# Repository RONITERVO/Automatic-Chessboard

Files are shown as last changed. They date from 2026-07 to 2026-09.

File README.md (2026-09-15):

# Automatic Chessboard

Arduino firmware for a CoreXY automatic chessboard with:

- two STEP/DIR stepper-motor drivers;
- an electromagnet for moving pieces;
- a multiplexed 8x8 reed-sensor matrix;
- a 16x2 I2C LCD and two-button interface; and
- the Micro-Max chess engine.

This is a substantially modified implementation of Greg06's
[Automated Chessboard](https://www.instructables.com/Automated-Chessboard/),
adapted around salvaged 3D-printer mechanics and the tested electronics
documented in this repository. See [design lineage and
attribution](ATTRIBUTION.md) and the repository's
[multi-license map](LICENSE.md) before redistributing it.

The [immersive 3D simulator](https://ronitervo.github.io/Automatic-Chessboard/) presents the complete assembly, chess pieces, setup process, physical controls, LCD, Arduino signal flow, wiring, and full-history replay in one shared React Three Fiber world. Visitors can use mouse, touch, or supported WebXR hands/controllers at real-world scale while the compiled production Nano HEX drives power-on, calibration, reed sensing, Micro-Max decisions, STEP/DIR motion, and magnet control. The standalone experience exposes Bluetooth as disconnected and never requests a real device. It is published automatically from `site/` after changes reach `main`.

## Demo

https://github.com/user-attachments/assets/5234de29-f910-4aed-a476-050bdca1a51d

## Hardware assumptions

The sketch uses the pin assignments and motion calibration in `global.h`. The
motor interface expects STEP/DIR drivers such as the A4988; motor current and
microstep selection are configured on the driver hardware.

For a complete beginner-oriented build, start with the
[`hardware` build guide](hardware/README.md). It includes protected power
wiring, a BOM, exact Nano/MKS Gen L V1.0 and 64-square sensor maps, staged assembly,
commissioning checks, diagrams, photographs of the working prototype, and
rework notes for the operational long PCB whose design predates the current
Bluetooth and A6 additions. Its archived KiCad source is reference-only, not a
current fabrication release. The 5 V buck output belongs on the Nano `5V` pin,
not `VIN`.

## Building

The release build is reproducible from PowerShell:

```powershell
./firmware/test.ps1 -InstallDependencies
```

It pins the AVR core and display libraries, validates the hardware contract,
runs tool tests, compiles the classic Nano and MKS Gen L V1.0 profiles, and
enforces flash/SRAM budgets. See [`firmware/README.md`](firmware/README.md) for the
modular source layout, explicit upload command, and contributor policy. The
main `.ino` can still be opened normally in Arduino IDE; its sibling `.ino`
tabs are compiled together automatically.

Review the pin assignments, travel calibration, limit-switch behavior, driver
current limit, and microstep settings before powering the motion hardware.

## Full validation without motion

When motors, piece magnets, or trustworthy reed readings are unavailable, run:

```powershell
./test-no-motion.ps1 -Port COM7
```

The workflow compiles the Nano firmware, enforces its memory budgets, exhaustively
tests the motionless `PLAN` / `DRAG` / `COMMIT` occupancy model, runs Windows and
Android planner/protocol/simulator tests, builds both apps, and optionally samples
the real Nano over USB. The COM probe is allowlisted to `HELLO 5.0.1`, `INFO`,
`TELEM`, and `BOARD`; it validates BOARD framing but does not require any particular
occupancy. It never uploads firmware or requests calibration, motor steps, magnet
power, or a chess move.

The probe first tries to keep DTR/RTS inactive. If a classic Nano does not
answer without its normal USB reset, use `-AllowSerialReset` only after checking
that firmware startup cannot energize the mechanism; this still does not send
an upload or any motion-capable protocol command.

This is the strongest release test possible without actuation, but it cannot prove
motor direction or step accuracy, magnet current/pickup/release, reed wiring and
orientation, mechanical clearance, homing repeatability, or physical collision
behavior. Those remain staged commissioning checks.

## Windows and Bluetooth companion

`windows_app` is the public-ready, open-source Windows monitor and companion for
this firmware. Windows runs Stockfish 18 and full chess rules while the Nano
retains motor timing, sensor scanning, calibration, limit checks, and Micro-Max
as a standalone fallback. It supports the Nano USB port, HC-08 BLE using the
default `FFE0`/`FFE1` service, and a no-hardware simulator for contributors.

Run `windows_app/setup.ps1` once, then `windows_app/run.ps1`. The visual Monitor
shows physical occupancy mismatches, carriage state, magnet command, limit
inputs, firmware memory, uptime, and connection freshness. Guided diagnostics,
structured logs, privacy-sanitized support bundles, optional local camera view,
automatic reconnect, and guarded developer controls are included. Start with
**Diagnostics -> Run safe diagnostics**; it never moves hardware. **Start game
and calibrate** intentionally begins physical movement.

The HC-08 receives commands on D10 through a receive-only software UART and
gets replies from hardware TX/D1. D0 remains dedicated to the onboard USB
bridge, so Bluetooth and USB transmitters never fight electrically. To free
D10, Button B/black limit uses analog-only A6 with a required external 10 kOhm
pull-up to 5 V. The HC-08 RX input must receive 3.3 V logic through a divider.
See `windows_app/README.md` for the complete wiring and first-start procedure.

Firmware 5.0.1 keeps the standalone two-button/LCD and Micro-Max play
experience while adding a small transactional executor for host-planned
collision-safe rearrangements. Windows can evacuate and restore blockers, stage
the main piece, and recursively clear trapped pieces; the Nano accepts only
straight orthogonal drags and proves the complete sensor frame before and after
each one. Capture removal is an explicit verified transaction step. An
`EDGEEXIT` companion routes the captured piece through empty square centres to
any available position beside `a1` through `a8`, moving another piece only when
all eight exits are genuinely disconnected. En passant, promotion
occupancy, and standard castling are included. Version 5.0.1 deliberately removes
the legacy `PLAY`, `PING`, and `STATUS` paths: both companion and Nano must run
the same release and complete the exact `HELLO 5.0.1` exchange before any normal
control or motion command is accepted. `STOP` and the single-byte `!` emergency
halt remain available before agreement for best-effort recovery.

For local Micro-Max play, firmware 5.0.1 automatically carries knights and
blocked direct moves through the shortest available sequence of empty,
orthogonally adjacent square centres. It retains manual placement only when no
empty route connects the move endpoints. If a capture itself cannot reach the
bin, the player may remove it when prompted; after confirmation, the Nano
reruns the route search and completes the AI move automatically when possible.

Boards with missing, intermittent, or deliberately unused reed switches can use
the explicit **Move by tapping app** mode in either companion. Both human and
Stockfish moves then originate in the app and use the same physical route
planner. The app and Nano maintain matching virtual occupancy and ignore reed
readings for that entire game. The user visually confirms every completed move;
any mismatch or lost connection stops play and requires inspection and a new
calibrated session. This is an explicit authority choice, never an automatic
fallback from failed sensors.

Reproducible resource-budgeted builds, measured calibration references, the
configurable connected endurance tool, the 30-second continuous-magnet timeout,
normalized sensor coordinates, guarded calibration/direct movement, and the
best-effort `!` halt remain available. Bluetooth and cameras are not safety
systems, so a local physical power cutoff remains required for remote operation.

## Android Bluetooth companion

`android_app` provides the same working range from a phone: native HC-08 BLE
with reconnect, live logical/physical board comparison, Stockfish 18 play,
the same collision-safe blocker rearrangement and verified route transaction as
Windows, guided safe diagnostics, phone and network-camera views, PGN export,
structured logs, privacy-sanitized support ZIPs, a hardware-free simulator,
guarded raw commands, and a persistent best-effort halt control. Every page uses
a fixed, adaptive layout with pagination instead of horizontal or vertical
scrolling.

Run `android_app/download-stockfish.ps1`, then open `android_app` in Android
Studio or run `android_app/gradlew.bat assembleDebug`. See
[`android_app/README.md`](android_app/README.md) for installation, safety, and
contributor guidance.

## Motor-driver configuration

`MOTOR_MICROSTEPS` in `global.h` must match the hardware configuration of both
motor drivers. For an A4988, the common modes are:

| Microsteps | MS1 | MS2 | MS3 |
| ---: | :---: | :---: | :---: |
| 1 | LOW | LOW | LOW |
| 2 | HIGH | LOW | LOW |
| 4 | LOW | HIGH | LOW |
| 8 | HIGH | HIGH | LOW |
| 16 | HIGH | HIGH | HIGH |

The current high-friction-drive profile remains in full-step mode
(`MOTOR_MICROSTEPS = 1`). Its measured working value uses a fixed fast step
interval; avoiding slow ramps prevents the prototype's strong low-speed
resonance. If the driver jumpers or wiring are changed later, change this
constant to the same value. The firmware then scales the steps per square,
homing limit, and step intervals to preserve the existing travel distance and
approximate physical speeds.

Set the driver current limit from the motor's rated phase current and the sense
resistors fitted to the particular driver board. For an A4988, consult that
board's documentation before using the common `Imax = Vref / (8 * Rsense)`
calculation; clone boards use different sense-resistor values. Never move a
driver or motor connection while motor power is applied.

## Calibration approach safety

Calibration always seeks the white switch before the black corner switch. If a
known trolley position is above rank 6, the unloaded head first moves down to
rank 6. If the black switch is already active, the head moves one full square
away to clear that lane. The staging move never travels toward the black switch.

During normal calibration both switches are approached one step at a time. The
white switch stays pressed while the black switch is found. Capture recovery and
developer reference calibrations use the same sequence. After both switches
establish the corner, the head moves directly to the exact e6 park offset with
no separate release/backoff stage or switch-specific release-distance setting.

The shared button inputs act only as endstops during calibration, so they cannot
abort calibration. Use the board's power switch for an emergency stop during
this sequence. Button emergency stops remain enabled for normal board and test
movements outside calibration.

Every successful calibration and endurance-test reference pass parks the head at
e6. This keeps the normal power-cycle and new-game starting position out of the
black-switch lane before the next white-switch approach.

## Power-cycle position memory

The firmware journals head positions across 32 EEPROM slots. Before the first
step of any motor movement it commits an `UNKNOWN` record. A new board-square
coordinate is committed only after the head reaches that stable endpoint. The
journal spreads writes across slots and commits each record last, so an
interrupted EEPROM write leaves the preceding complete record available.

Immediately after power-up the LCD displays `LAST HEAD` and either the saved
square or `??`. A saved coordinate is used only to stage calibration safely; it
does not bypass calibration or enable normal movement. For example, a head
saved at e8 first moves away from the corner to rank 6 before seeking the white
calibration switch.

Switching power off while the head is stopped preserves its displayed square.
Switching power off during movement produces `POS UNKNOWN` on the next boot,
because no coordinate can safely represent a partially completed move. The
saved square also assumes the unpowered head has not been moved by hand or
shifted mechanically after the motors lose holding torque.

Calibration is blocked when the position is unknown and the black switch is
not already active. The LCD asks for the unpowered head to be placed at rank 6
or below; after the next startup, select calibration and confirm `A=READY`.
This recovery confirmation is also required on the first boot after installing
firmware that has no valid position journal yet.

## Connected endurance test

Firmware 4.0 and later move the former fixed on-device AI self-play workload to the
configurable [`firmware/endurance_test.py`](firmware/endurance_test.py) tool.
Firmware 4.4 uses that guarded, developer-only `PATH` command only for
horizontal, vertical, and 45-degree square-centre paths; continuous knight or
S-shaped travel is deliberately rejected.
The magnet is forced off, results are logged on the computer, cycle count and
reference frequency are configurable, and both homing step counts are compared
against a measured baseline. See [`firmware/README.md`](firmware/README.md) for
the exact command and physical safety requirements.

This test detects accumulated position drift using the existing switches. It
cannot prove that no individual missed step was later cancelled in the opposite
direction; detecting every stall in real time requires motor encoders or a
driver with suitable diagnostic feedback.

## Builder geometry measurement

Firmware 4.5 keeps board geometry as four compile-time constants, with no
geometry EEPROM or runtime configuration. The Windows and Android companions
provide the measurement interface so the Nano's local controls stay focused on
play and calibration. After normal calibration, open **Board alignment** on
Windows or **Move > Align board** on Android, select a square, and start the
recommended head-only session. Use the four one-step controls until the head is
visually centered, then record the point. A magnetic marker is optional and
requires the separate safety confirmation.

Measure two widely separated squares with different files and ranks. The apps
show the exact four source values to edit in [`global.h`](global.h), including
correct handling of non-default microstepping. The session never writes EEPROM
or changes installed geometry, and it reverses all nudges when finished. It
marks the head position unknown before the first nudge, so calibration is
mandatory even after disconnect or power loss.

For terminal-only work, send `GEOMETRY`, then `ALIGN <square> H`, use `NUDGE
X+|X-|Y+|Y-`, record the `ALIGN ACTIVE` offsets, and finish with `ALIGN END`.
The optional offline calculator accepts the two recorded reports:

```powershell
python ./firmware/geometry_calculator.py `
  "GEOMETRY a2 X+3 Y-1" "GEOMETRY h7 X+10 Y-6"
```

Edit the four reported constants, upload, calibrate again, and verify at least
four widely separated squares. This corrects translation and independent axis
scale; a rotated, skewed, or nonuniform board must be aligned mechanically.
The removed local maintenance carousel and duplicate sensor screen reduce Nano
flash and SRAM; both apps and the `BOARD` command retain complete diagnostics.

## Piece-retention travel planner

The standalone planner accepts direct carried moves only when
their square centres share a file, rank, or diagonal. It does not attempt a
continuous knight or S-shaped carry. Connected play represents those moves as
separate verified square-centre drags. Capture removal and the rook part of
castling retain explicit horizontal/vertical segments to reach their
necessary off-board or temporarily obstructed destinations.
Standalone carries also preflight every traversed square; diagonal steps
require both shared orthogonal corner squares to be empty. An unsafe direct
carry becomes a manual, sensor-verified move before the magnet is energized.

If the local Micro-Max opponent selects a knight move, the LCD shows the exact
`MANUAL` instruction instead of attempting unsafe travel. Move that piece by
hand and press A; the Nano verifies the reed-switch occupancy before continuing
the same game. B returns to the menu.

Before an automatic standalone capture, the Nano runs a bounded breadth-first
search through empty orthogonal square centres to any free `a1`-`a8` exit. It
therefore takes winding routes around unrelated pieces without moving them. If
the captured piece is disconnected from every exit, standalone play uses the
same `MANUAL` instruction and sensor-verified continuation instead of risking a
collision. Connected play can additionally evacuate and restore pieces when no
empty route exists.
Manual captures are deliberately two-stage: remove the displayed captured
square and press A. If the remaining AI carry is queen-aligned and every
traversed square and diagonal corner is clear, the Nano resumes that move
automatically. Otherwise it displays the complete `MANUAL` move for the player
to perform before pressing A again. This lets occupancy-only reed switches
prove that the destination was actually emptied before the AI piece replaced
it.

For connected play, `windows_app/routing.py` searches labeled board
configurations. It uses only orthogonal square-to-square carried paths, so the
physical diagonal-clearance constraint is satisfied conservatively. Turning
paths are split at square centres into straight sensor-verified `DRAG` commands.
The search minimizes disturbed pieces first, then actual magnet pickups,
distance, and turns. Hardware-validated side-adjacent pieces do not penalize an
otherwise empty orthogonal route. Time, node, parking, corridor,
temporary-piece, and recursion limits prevent unbounded optimization work.
Before search,
the planner classifies the exact 8×8 labeled-pebble reachability cases; ordinary
chess positions have enough empty squares to be structurally reachable. If
bounded optimization cannot finish, a reversible dense-board constructor can
return a replay-validated safe plan. It is marked non-optimal. Failure still
stops the move when neither method produces a validated plan.

Every corridor ends on an exact whole-step destination, with no interpolation
rounding to accumulate between moves. Firmware 4.4 also removes unequal-ratio
CoreXY interpolation below every caller: each displacement is one or more pure
horizontal, vertical, or 45-degree segments. Hardware validation uses a `1000`
microsecond half-period for start, carrying, and unloaded motion. Keeping these
equal intentionally avoids the mechanism's strong low-speed resonance.

## Captured-piece bin

Captured pieces are released into the bin along the calibration side. Supported
5.0 builds require unobstructed bin and carriage clearance beside the complete
`a1`-`a8` edge; this is the geometry used by the repository designs.
The calibrated e6 park position places the left limit at approximately `x = 0.35` in
board-square coordinates; the playing-field edge is `x = 0.50`. Release uses a
conservative `x = 0.48` center line, just outside the playing field and about
25 full steps away from the limit switch.

For every capture, the piece reaches an `a`-file square centre and then follows
that rank directly to the left-side release point. The final axial segment uses
the normal carrying speed and finishes before magnet release.
The head remains stationary through the magnet's release delay and for another
400 ms while the piece falls into the bin. It then immediately
homes both axes from the nearby calibration side and restores the known e6
position before moving the AI piece. Nothing is stored on the travel rail, so
later captures cannot collide with earlier ones.

Capture behavior remains covered by normal standalone and connected game paths.
The magnet-free endurance test intentionally focuses on repeatable production
board travel; capture-bin testing requires a guarded physical-piece test.

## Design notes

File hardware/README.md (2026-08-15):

# Hardware build guide

This folder is the electrical build contract for firmware **5.0.1**. It is
intended to be detailed enough for a school lab or first-time builder without
pretending that the prototype PCB is a manufacturing-ready product.

Start with these documents, in order:

1. [Safety rules](SAFETY.md)
2. [Bill of materials](BOM.md)
3. [Wiring and pin contract](WIRING.md)
4. [Mechanical interface](MECHANICAL.md)
5. [Working prototype and enclosure reference](PROTOTYPE.md)
6. [Staged assembly](ASSEMBLY.md)
7. [First-power commissioning](COMMISSIONING.md)

Builders replacing the Nano and external driver/transistor assembly with the
integrated ATmega2560 board in the supplied photograph should instead follow
the complete [MKS Gen L V1.0 profile](MKS_GEN_L_V1.md). It retains the same
sensor/square map and mechanics but has its own connector-level pin contract.

The [`printFiles`](printFiles/README.md) directory contains the project's 3D
print models, separately attributed third-party models, and optional printable
20 x 20 mm V-slot components for builders evaluating an alternative to
aluminium extrusions and brackets.

This hardware is a modified 24 V implementation of Greg06's
[Automated Chessboard](https://www.instructables.com/Automated-Chessboard/),
rebuilt around salvaged 3D-printer motion parts. The base project is credited
in the repository's [attribution notice](../ATTRIBUTION.md); its CC BY-NC-SA
license and this repository's license exceptions are mapped in
[`LICENSE.md`](../LICENSE.md).

The machine-readable sources of truth are [connections.csv](connections.csv)
and [sensor-map.csv](sensor-map.csv). Run `./hardware/validate.ps1` from the
repository root after changing hardware pins, firmware pins, or the sensor map.

## What is authoritative

| Artifact | Status | Use |
| --- | --- | --- |
| `WIRING.md`, diagrams, and CSV tables | Current | Build firmware 4.6.0 Nano hardware from these |
| `MKS_GEN_L_V1.md` and `mks-gen-l-v1-connections.csv` | Current alternative | Replace Nano, external drivers, and TIP120 with an MKS Gen L V1.0 |
| Firmware constants in `global.h` | Current | Pin and motion configuration |
| Commissioning checklist | Current | Required before first movement |
| [Photographed working build](PROTOTYPE.md) | Tested prototype | Evidence for the mechanism, enclosure integration, controller rework, component choices, and 0.720 V driver setting |
| `reference/legacy-controller` | Working fabricated prototype with historical design files | Reuse an existing board only with the documented external rework; do not treat it as a current fabrication release |

The fabricated legacy PCB operates in the photographed prototype after adding
external wiring and resistors. Do **not** send its archived design to a
manufacturer unchanged: it predates the current Bluetooth and A6 changes and
intentionally leaves required wiring out of the PCB design. No Gerbers are
published.

## System at a glance

Power and protection diagram

Controller wiring diagram

Reed sensor wiring diagram

## Tested prototype versus public build

The existing prototype proves the electrical and firmware arrangement, but it
does not yet contain every protection required by this guide.

| Item | Existing prototype | Public build requirement |
| --- | --- | --- |
| 24 V supply | Unbranded 24 V, 10 A brick | Regulated, enclosed supply; 3 A minimum, 5 A recommended |
| Main fuse | Not installed | 3 A time-delay starting value, at least 32 V DC, close to inlet; 5 A maximum only after measuring load |
| Emergency cutoff | PSU rocker switch | Latching, reachable switch rated for at least 30 V DC and 5 A |
| Reverse polarity | Not installed | 30 V-or-higher, 5 A-or-higher protection module or equivalent |
| Logic power | 5 V buck currently connected to Nano `VIN` | Regulated 5.0 V connected to Nano `5V` |
| Driver wake | `RESET` and `SLEEP` tied together; no external 5 V trace | Tie both together and explicitly connect them to 5 V |
| Driver STEP/DIR defaults | Four 10 kohm pull-downs installed and tested | One independent 10 kohm pull-down from every `STEP` and `DIR` input to logic GND |
| Driver surge capacitor | 100 uF, 50 V at each carrier | Same, mounted directly across each `VMOT`/`GND` pair |

The protections are not cosmetic. A 10 A supply can deliver far more fault
current than the thin wires and modules can survive. The fuse protects wiring;
the cutoff gives the operator a dependable local stop. Bluetooth, software,
limit switches, and the Nano are not emergency-stop devices.

## Known measurements from the working board

- Board: 300 x 300 mm; each square: 37.5 x 37.5 mm.
- Reed-to-piece gap: approximately 0.2 mm in the printed tiles.
- Drivers: red StepStick-compatible carriers marked `HR4988SQ`, with two
  `R100` (0.10 ohm) sense resistors and heatsinks.
- Driver reference voltage: 0.720 V from potentiometer metal to driver GND.
  For this exact `R100` carrier, `0.720 / (8 x 0.10) = 0.90 A` peak limit.
- Driver mode: full step; `MS1`, `MS2`, and `MS3` low/open.
- Motor supply capacitors: 100 uF, 50 V electrolytic, one per driver.
- Electromagnet: H2520, 24 V, 2.8 W (about 117 mA nominal).

The JGAurora A3S donor motors no longer have labels, and no reliable
manufacturer phase-current specification was found. Treat 0.720 V as a tested
prototype setting, not a value to copy onto a different driver or motor.

## Design boundary

This documentation defines the low-voltage electronics and the mechanical
interfaces expected by the firmware. It does not define a certified product,
mains-voltage wiring, a sellable PCB, or a production enclosure. Builders may
change the frame, rails, belts, tiles, and capture bin if the electrical pin
contract, 37.5 mm square pitch, homing behavior, and motion calibration remain
consistent. Firmware 5.0 also assumes the bin and carriage have unobstructed
release clearance along the complete left edge beside `a1` through `a8`.

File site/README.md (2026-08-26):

# Immersive Automatic Chessboard simulator

This Vite + React Three Fiber application presents the Automatic Chessboard as one continuous three-dimensional object. The procedural hardware model, chess pieces, setup trays, LCD, buttons, Arduino signal view, wiring guide, and rewind controls all occupy the same world. There is no duplicate flat chessboard UI.

The model is authored in centimetres and mounted into the scene at `0.01` scale, so one scene unit is one metre in WebXR. It sits at real table height and the same R3F pointer handlers accept desktop mouse rays, touch input, XR controllers, tracked hands, gaze, and transient XR pointers.

## Experience

- Orbit with drag, zoom with the wheel or pinch, and pan with the secondary pointer gesture.
- Press the modeled `POWER`, `A`, `B`, or illuminated next-action control exactly as on the physical board.
- During setup, select or drag each piece from the two physical side trays to its expected reed square. `AUTO/FINISH SETUP` remains available when a visitor wants to continue without placing all 32 pieces manually.
- During play, press or drag a piece once. Legal destinations illuminate on the physical tiles. The same interaction handles the firmware's manual AI-placement fallback, including knight moves.
- Use the physical timeline to step, play, scrub any recorded point, and return to the live Arduino. Meaningful events and motion stay frame-accurate; unchanged idle data is shared and sampled at a lower cadence for long sessions.
- Switch among `PLAY`, `BRAIN`, `X-RAY`, and `WIRE`. Brain mode exposes live reed input, AVR program counter and loop, firmware state, Micro-Max, STEP pulses, moving head, and magnet output inside the exploded board. Wiring mode animates all source-of-truth harness stages.
- Double-press a modeled component to open its spatial build card. Its physical controls open the source/recommendation, persist an owned mark, hide the part, or close the card; the rear build dock reports progress and restores all hidden parts.
- Press `VR` or `AR` on a supported secure-context browser. Unsupported browsers keep the complete desktop/touch experience and report why XR could not start.

The simulation executes the compiled production Nano HEX with AVR8js. It models the PCF8574/I²C LCD backpack, four 16-channel reed multiplexers, physical buttons/endstops, EEPROM, CoreXY STEP/DIR outputs, electromagnet, and UART telemetry at their electrical boundaries. Motor movement follows the step pulses and timing emitted by the real firmware.

Bluetooth is deliberately disconnected in standalone mode. The worker already has a byte/transport boundary for a future user-authorized Web Bluetooth adapter, but the page does not request or connect to hardware today.

This is a command-accurate hardware visualization, not a rigid-body physics simulation. It does not claim to model belt stretch, inertia, missed steps, magnetic field strength, piece collisions, or real-world tolerances.

## Architecture

- `src/firmware-core.js` and `src/firmware-worker.js`: real AVR runtime and peripheral adapter.
- `src/firmware-session.js`: framework-facing orchestration, chess rules, guided actions, announcements, and complete replay history.
- `src/model.js` and `src/wiring.js`: reviewable procedural hardware and harness geometry sourced from the hardware CSV files.
- `src/immersive/`: the shared R3F scene, spatial controls, physical pieces, Arduino signal visualization, responsive camera, and WebXR input surface.
- `src/main.jsx`: React application entry point.

The boundary is intentional: hardware complexity stays in the adapter, orchestration stays independent of rendering, and scene components only translate state into visible objects and pointer actions.

## Development and verification

```powershell
./firmware/build.ps1 -HardwareProfile nano
cd site
npm install
npm run validate
npm test
npm run build
npm run dev -- --host 127.0.0.1 --base /Automatic-Chessboard/
```

Open `http://127.0.0.1:5173/Automatic-Chessboard/`. Test the running page in a real browser at that deployment subpath; a successful build alone is not an interaction test. The GitHub Pages workflow performs the resource-budgeted Nano compile before building the site, so it cannot silently deploy a stale hand-maintained firmware copy.

The validation gate preserves the 23 modeled component groups, 84 wiring connections, 64 unique reed channels, CoreXY geometry, production-firmware boundary, spatial interaction surface, brain visualization, and absence of a duplicate 2D board.

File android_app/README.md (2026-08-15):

# Automatic Chessboard for Android

This is the phone-first companion for matching firmware 5.0.1.
It covers the Windows
companion's current Bluetooth workflow while keeping Android, chess rules,
Stockfish, protocol handling, and screen rendering separate enough to extend.

## Current capability

| Area | Android behavior |
| --- | --- |
| Connection | Native BLE scan, saved-device reconnect, HC-08 FFE0/FFE1 GATT, exponential retry, 20-byte writes |
| Monitor | Logical pieces, all 64 occupancy sensors, missing/extra squares, carriage estimate, magnet command, controls, memory, uptime, stale-state health |
| Move | Tap a square for head-only movement or tap an occupied source plus empty target to carry a piece; in-app calibration and fresh e6 telemetry verification are required |
| Align board | Measure two user-chosen squares with precise X/Y nudges and copy exact `global.h` source values; head-only is the safe default and a magnetic marker is optional |
| Play | Full legal rules through chesslib, official Stockfish 18, human White/Black, reed-verified or app-controlled play, collision-safe blocker rearrangement, castling/en-passant/promotion, paged move history, PGN export |
| Diagnostics | Connection, INFO, TELEM, BOARD, controls, Stockfish, and camera checks; no motion commands |
| Camera | Local phone cameras, encrypted HTTPS streams, or unencrypted RTSP streams supported by Android; explicit JPEG snapshots only |
| Developer | Structured and raw-equivalent protocol timeline, pagination, documented-command allowlist, motion lock plus confirmation, simulator `SIMMOVE` |
| Support | JSONL session logs, copied diagnostic summary, sanitized ZIP with no frames, PGNs, camera credentials, or Bluetooth address |
| Safety | Persistent HALT button, separate single-byte `!` path, motion polling pause, stale-state warnings, no remote fault clearing |

The firmware restricts direct manual carries to square centres on the same file,
rank, or diagonal. The Play planner continues to handle knights and other
turning moves as separate orthogonal square-centre `DRAG` operations.

On the Play page, **Moves: Reeds** keeps the existing sensor-verified workflow.
Tap it before starting to select **Moves: App** for absent or unreliable reed
switches. Confirm the standard starting position, then select every human move
by tapping its source and destination; the mechanism executes both human and AI
moves. Reed input is ignored for the whole game. The phone previews and asks for
visual confirmation after every completed chess move. A mismatch, connection
loss, halt, or route error ends the session and requires inspection and a new
calibration. Never move pieces by hand in this mode except when promotion
replacement is explicitly requested.

The phone plans automatic moves as labeled board
rearrangements. It can evacuate and restore blockers, stage the main piece while
a return corridor is used, and recursively free trapped blockers. Carried paths
are orthogonal and turning paths become separate straight drags at square
centres. After capture removal and every drag, Reed mode verifies all 64 physical
switches; App mode verifies the Nano's independently maintained virtual occupancy
and then requires whole-board visual confirmation after the completed chess move.
A timeout or disconnect after physical motion stops the session and requires
inspection; it is never retried from an assumed state.

For captures, a piece is routed through empty square
centres to any available position beside `a1`-`a8`. A route around obstacles is
always preferred over moving another piece; the parking search is used only
when every edge exit is disconnected.

The **Route** button on the Play page adjusts the bounded search duration and
maximum number of temporarily moved pieces without adding a scrolling settings
page. Version 5.0.1 always uses the verified route transaction and refuses motion
until app and Nano report the same exact software version.

No page contains a `ScrollView`, horizontally scrolling container, or vertically
scrolling list. Dense histories and logs use explicit pages. Portrait and
landscape layouts recompute on rotation, and system-bar insets are respected.

Cleartext HTTP camera URLs are rejected with an explicit warning. Use HTTPS for
encrypted transport. Plain `rtsp://` is not encrypted and should be used only on
a trusted local network or inside a separately secured tunnel; the current
Android media client does not advertise RTSPS support.
Devices without Bluetooth Low Energy can still install the app and use its safe
simulator; only real-board scan and connection are unavailable.

## Build

Requirements: Java 17 and Android SDK 35 or newer.

The official Stockfish 18 armv8 binary is large and is intentionally not stored
in normal Git history. On Windows, download and verify the official release:

```powershell
cd android_app
.\download-stockfish.ps1
.\gradlew.bat testDebugUnitTest lintDebug assembleDebug
```

The script verifies both the release tar SHA-256 and extracted binary SHA-256.
The APK is written to `app/build/outputs/apk/debug/app-debug.apk`. The current
package contains arm64-v8a Stockfish, matching modern 64-bit-only Android phones.
The rest of the app supports API 26+. Add another verified binary under the
matching `jniLibs/<abi>/libstockfish.so` directory to support another CPU ABI.

Install a development build:

```powershell
adb install -r app\build\outputs\apk\debug\app-debug.apk
```

## First safe use

1. Keep motor/magnet power physically removable and the mechanism clear.
2. Tap **Connect**, scan, and choose the HC-08. The strongest likely HC-08 is
   ranked first, but its address is still shown for confirmation.
3. Open **Checks** and tap **Run checks**. This sends only HELLO, INFO, TELEM, and
   BOARD requests.
4. Confirm firmware, sensor, and input results. Released A6 should normally be
   at least 700 and near 1023.
5. Use **Board** to reconcile every red missing and orange extra square.
6. Test physical limit behavior locally before **Start + calibrate**.

For a differently sized or positioned playing field, use **Move > Align board**
after a successful calibration. Select a square, start head-only measurement,
nudge until centered, and record it. Repeat at a widely separated square with a
different file and rank. **Result** shows copyable firmware coefficients and
correctly accounts for non-default microstepping. The app does not write EEPROM
or modify firmware. Every measurement leaves the head unhomed, including after
disconnect or interruption, so recalibration is mandatory before play.

The red **HALT** control is best-effort radio delivery, not an emergency-stop
system. It intentionally leaves the carriage position unknown. Cut physical
power if motion continues or the link is unavailable.

## Contributor start

Read [`ARCHITECTURE.md`](ARCHITECTURE.md), then run the unit tests. Use
**Simulator** for UI and game-flow changes; `SIMMOVE e2e4` in **Dev** represents
a physical human move. The simulator implements the complete route transaction
without hardware. Protocol changes require one coordinated app/firmware version
bump, typed parsing, simulator behavior, and tests before UI work.

Never add a generic "send anything" bypass. Read-only, session-control, motion,
emergency, and unknown commands are deliberately separate. Never make a stale
snapshot look live, silently merge sensor occupancy with logical identity, or
clear a physical fault from the phone.

## Privacy and files

Logs stay in app-private storage and are capped to the newest 20 sessions.
Support bundles redact BLE addresses, network camera URLs, and URL credentials.
Camera frames and games are included only when the user explicitly saves them.
Uninstalling the app removes private logs and settings.

This app is GPL-3.0-or-later. See [`THIRD_PARTY_NOTICES.md`](THIRD_PARTY_NOTICES.md);
complete Apache licensing and the Commons Lang NOTICE ship in `assets/third_party/`
inside every APK.

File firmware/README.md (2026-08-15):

# Nano firmware development

Firmware 5.0 keeps the controller responsible for deterministic motion, sensor
normalization, safety interlocks, persistence, the two-button/LCD experience,
and a compact standalone chess opponent. Full chess rules, Stockfish, rich
monitoring, and configurable development workloads belong on a connected phone
or computer.

## Release 5.0.1 behavior

Firmware and both companions now use one exact release contract. A companion
must send `HELLO 5.0.1` on its USB or Bluetooth transport before any control or
motion command; the Nano answers only an exact match. `INFO`, `TELEM`, `BOARD`,
`STOP`, and the byte-level `!` emergency halt remain available for diagnosis and
recovery. The old `PLAY`, `PING`, and `STATUS` commands and capability-string
negotiation were removed. Install matching app and firmware releases together.

Standalone capture removal now searches the complete 8x8 empty-square graph.
It chooses a shortest orthogonal route to any of the eight a-file exits and
compresses it into straight, fast, full-step square-centre carries. This uses
stack workspace only—no EEPROM and no global SRAM. If every exit is genuinely
disconnected, the LCD requests the existing sensor-verified manual move.

Standalone Micro-Max piece movement uses the same bounded graph. A clear move
on one file, rank, or diagonal remains a direct carry. A knight or any piece
whose direct corridor is blocked instead follows a shortest route through empty
orthogonally adjacent square centres, compressed into straight full-step runs.
No stationary piece is moved. The LCD requests manual placement only when the
source and destination are genuinely disconnected.

All supported builds assume the capture bin and carriage clearance extend along
the complete left edge beside `a1` through `a8`.

## Release 4.8.0 history

Firmware 4.8 advertises `EDGEEXIT`. During a deferred capture, a capable phone
or computer may use ordinary verified `DRAG` segments to carry the captured
piece through any empty square-centre path to any available `a1`-`a8` exit.
The Nano follows that capture square through every proven transition and allows
`REMOVE` only while it is still present. The bounded host search therefore uses
zero temporary pieces whenever any edge exit is reachable and invokes the same
parking/dependency search only when every exit is genuinely disconnected.

Version 5.0 supersedes the compact L-only standalone routing described by this
historical release.

## Release 4.7.0 behavior

Firmware 4.7 makes capture removal an explicit `REMOVE` step inside a verified
route transaction. `PLAN` no longer moves a captured piece on new companions.
The phone or computer can first use the existing bounded rearrangement search
to park pieces blocking all left-bin lanes, request `REMOVE`, prove the complete
board frame, finish the main move, and restore every parked piece. This closes
positions where a legal capture previously failed with `ERR BAD ROUTE` before
the planner could clear an exit. Firmware 4.1-4.6 remains supported through
capability detection; that compatibility negotiation was removed in version 5.0.

## Release 4.6.0 behavior

Firmware 4.6 adds explicit app-authoritative play for boards with absent or
unreliable reed switches. `START W APP` / `START B APP` calibrates, seeds the
Nano's virtual occupancy to the standard position, and then accepts the same
bounded `PLANROUTE` transactions for both human and computer moves. During that
session `BOARD` reports the independently tracked virtual frame and no reed
input is used for game decisions. The apps require every human move to be
selected on screen and require visual confirmation after every completed chess
move. A mismatch, route error, halt, or connection loss ends the session; it
never silently changes between virtual and reed authority.

This mode does not pretend to detect a dropped piece or missed step. The app and
Nano cross-check command-derived occupancy, while the person watching the board
is the only physical feedback. Reed-verified play remains the default.

## Release 4.5.0 behavior

Firmware 4.5 replaces the local maintenance carousel with a simpler startup:
Button A starts standalone play and Button B calibrates. Complete sensor,
telemetry, switch, motor-jog, and board-registration tools remain available to
connected builders, where they can explain results and be tested without using
scarce Nano UI memory.

Board registration is a recoverable host-guided session. `GEOMETRY` reports the
compiled pitches, park offsets, and microstep factor. `ALIGN <square> H|M`
visits a chosen square, and four `NUDGE` commands move one logical X/Y step at a
time. Head-only mode keeps the magnet off; optional marker mode pulses it only
during each step. The firmware journals the carriage as unknown before nudging,
bounds each axis to 60 steps, reverses all accumulated nudges on `ALIGN END`,
and still requires calibration afterward. It never writes geometry to EEPROM.
The Android and Windows apps turn two widely separated measurements into exact
`global.h` source values.

Firmware 4.4 made queen-aligned stepping a firmware-wide invariant. Every raw
CoreXY displacement is executed only as horizontal, vertical, or exact
45-degree segments; an unequal X/Y request is decomposed instead of using an
interpolated step ratio. Direct carried commands accept only square-centre
moves sharing a file, rank, or diagonal. Knights and other turning carries must
use the connected `PLANROUTE` executor, which already stops and verifies at
square centres between straight `DRAG` commands. Unsupported legacy/direct
routes fail before capture removal, magnet pickup, or head movement.

Firmware 5.0.1 preserves that segment-level invariant while adding the compact
standalone graph search described above. It never restores a continuous
knight/S-curve or an unequal-ratio motor command.

When no automatic capture route exists, the manual fallback still uses two
sensor-verified phases only when necessary. Remove the captured piece and press
A; the Nano refreshes all sensors and retries both its direct and shortest-route
carried paths. It moves the AI piece automatically when now reachable. Only a
still-disconnected destination requires manual placement and a second A press.
The empty intermediate target closes the ordinary-capture identity ambiguity
that cannot be detected when a destination is occupied both before and after.

Firmware 4.3 added an explicit `mks-gen-l-v1` build profile for the integrated
ATmega2560 board. It preserves the same deterministic runtime, standalone play,
geometry, protocol, and 64-square sensor map while using the MKS X/Y driver
sockets, HE0 MOSFET, labeled expansion headers, full-duplex Serial2 Bluetooth,
and software-I2C LCD wiring. See `hardware/MKS_GEN_L_V1.md`. The Nano remains
the default and retains tight 29900-byte flash / 1115-byte global-SRAM budgets.

The Nano still works without a companion: calibration, starting-position
validation, human-vs-Micro-Max chess, physical captures/castling/en-passant,
EEPROM position recovery, LCD guidance, and two-button controls remain local.
Full 64-square sensor inspection and board registration remain available from
either app or a serial terminal. Removing the nested local maintenance UI makes
the ordinary controls clearer and returns memory to long-term maintenance.

Connected USB/BLE clients retain remote games, occupancy/telemetry, safe
diagnostics, app calibration, head-only and sensor-verified piece movement, and
best-effort `!` halt. The fixed on-device 200-ply AI self-play test is the only
deliberately removed workflow; the configurable logged endurance tool below is
its more useful connected replacement. It is unavailable without a companion,
but its absence does not affect playing or servicing the board.

Firmware 4.1 advertises `PLANROUTE`. A trusted host opens a fixed-width `PLAN`,
sends one or more straight orthogonal `DRAG` commands, and finishes with
`COMMIT`. The Nano compares the full normalized reed frame before the plan,
before and after every drag, and before commit. It independently rejects stale
state, occupied destinations, blocked corridors, incomplete capture/castling
occupancy, and unexpected sensor transitions. Complex evacuation, restoration,
staging, and recursive clearing remain host responsibilities so Nano memory and
motion behaviour stay deterministic. See `windows_app/FIRMWARE_PROTOCOL.md`.

Firmware 4.5 provides the same board-registration work through either companion
or a guarded serial terminal. Calibrate first, read `GEOMETRY`, then collect two
widely separated `ALIGN ACTIVE` reports whose files and ranks both differ. The
apps calculate the answer directly. A terminal-only builder can use the formulas
in `global.h` or the optional offline calculator:

```powershell
python ./firmware/geometry_calculator.py `
  "GEOMETRY a2 X+3 Y-1" "GEOMETRY h7 X+10 Y-6"
```

Edit `FILE_PITCH_STEPS`, `RANK_PITCH_STEPS`, and both
`CALIBRATION_PARK_*_STEPS` values in `global.h`, upload, calibrate again, and
verify several separated squares before enabling play. The mode reuses normal
state storage, never changes EEPROM geometry, and makes calibration mandatory
after every session.

For deterministic limit-input commissioning, send `SWTEST` from USB or the
guarded developer console and follow its `PRESS A`, `RELEASE`, and `PRESS B`
prompts. Unlike ordinary telemetry, the test temporarily owns the shared
button/limit inputs so standalone menu actions cannot consume the press. It
never moves hardware and forces the magnet off before sampling.

For one-driver-at-a-time commissioning, firmware 4.0+ advertises `DEVJOG`.
`JOG W+`, `JOG W-`, `JOG B+`, and `JOG B-` pulse only that driver for 20 full
steps. They are idle-only motion commands, keep the magnet off, and deliberately
invalidate the carriage coordinate so calibration is mandatory afterward.
Disconnect the untested driver's VMOT and the magnet branch before using them.

## Source layout

- `Automatic_Chessboard_V3_27_i2c_value.ino` owns setup, the top-level state
  machine, and all mutable state.
- `global.h` contains the pin/timing contract, enums, types, and declarations.
- `FirmwareStandalone.ino` implements the no-companion play experience.
- `FirmwareHost.ino` implements the bounded USB/BLE protocol and remote play.
- `FirmwareSensors.ino` scans the reed matrix and tracks human moves.
- `FirmwareMotion.ino` owns CoreXY stepping, calibration, and path planning.
- `FirmwarePieces.ino` implements captures, castling, and carried moves.
- `PositionJournal.ino` owns power-loss-safe EEPROM position records.
- `Micro_Max.cpp` is the separately attributed standalone engine adaptation.

Arduino concatenates the `.ino` tabs into one translation unit, which keeps the
classic Nano build simple while separating responsibilities for contributors.
No dynamic `String`, heap allocation, or unbounded input buffer is used.

## Reproducible build

From the repository root:

```powershell
./firmware/test.ps1 -InstallDependencies
```

This installs pinned `hd44780` and `SoftwareWire` dependencies when requested,
validates the
hardware/firmware pin contract, runs developer-tool tests, compiles for
`arduino:avr:nano:cpu=atmega328old` and `arduino:avr:mega:cpu=atmega2560`, and
enforces both profiles' flash/global-SRAM budgets.
Later runs can omit `-InstallDependencies`.

Upload is intentionally explicit:

```powershell
./firmware/build.ps1 -Upload -Port COM7
```

The MKS alternative must always be selected explicitly:

```powershell
./firmware/build.ps1 -HardwareProfile mks-gen-l-v1 -Upload -Port COM11
```

Disconnect 24 V motor/magnet power before ordinary firmware uploads. Uploading
or connecting must never begin movement.

## Motionless release validation

From the repository root, the complete hardware-free workflow is:

```powershell
./test-no-motion.ps1 -Port COM7
```

`route_transaction_model.py` is an independent occupancy-only digital twin of
the Nano executor. Its tests exhaustively cover every clear straight drag, every
non-straight rejection, every possible intermediate corridor blocker, Plan A
evacuation/restore sequencing, capture, en passant, promotion, both standard
castles, exact commit/cancel behavior, emergency halt, and injected stale or
failed sensor transitions. No model code is compiled into the Nano.

`non_motion_serial_test.py` samples a connected Nano using a hard allowlist of
only `HELLO 5.0.1`, `INFO`, `TELEM`, and `BOARD`. It checks exact release identity,
framing, magnet-off telemetry, and repeated serial stability. Reed
occupancy is recorded but deliberately not judged. The probe cannot send an
upload, calibration, movement, magnet, transaction, stop, or emergency command.
Some Nano USB adapters can reset when their serial port opens even with DTR held
inactive; normal firmware startup therefore remains part of the magnet/STEP-low
safety contract.

If the Nano does not answer with DTR held inactive, rerun the root workflow with
`-AllowSerialReset` after making startup electrically safe. This permits only
the ordinary USB DTR reset; the command allowlist remains unchanged.

Motionless validation does not replace commissioning of motor direction and
step retention, magnet pickup/release, reed mapping, limit switches, carriage
clearance, or real-piece collision behavior.

## Connected endurance test

The old fixed 200-ply AI-vs-AI service routine consumed scarce Nano flash and
SRAM and could not be configured or logged. Firmware 4.0+ replaces it with the
magnet-free `PATH` developer command and a USB tool:

```powershell
python ./firmware/endurance_test.py --port COM7 --cycles 40 --confirm-motion
```

The test exercises horizontal, vertical, and both diagonal queen-aligned paths,
returns to e6, re-homes periodically, and compares both measured step counts
with an e6 baseline. It requires motor power and causes real movement. Remove all pieces,
keep the physical cutoff within reach, and never treat the `!` radio/USB halt as
a certified safety function.

## Resource policy

The 5.0 Nano build uses 29534 bytes of flash and 1091 bytes of global SRAM.
`build.ps1` rejects growth beyond 29900/1115 bytes, leaving 1186 bytes of
physical flash and 957 bytes for stack/local runtime state. Despite full-board
standalone bin routing, 5.0 saves 268 flash bytes and 24 global SRAM bytes versus
4.8. The packed
three-snapshot board representation uses 24 bytes instead of 192 bytes and is
reused as either reed-derived or command-derived occupancy.

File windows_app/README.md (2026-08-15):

# Open Automatic Chessboard Monitor for Windows

This is the public, open-source Windows companion for the Arduino Nano automatic
chessboard. It is designed both for ordinary players and for developers who may
need to observe and diagnose a board from across a room using Bluetooth and an
optional camera.

The interface leads with visual state rather than serial text. It shows the
logical chess position, all 64 physical occupancy sensors, missing or unexpected
pieces, the estimated carriage square, magnet command state, both button/limit
inputs, controller state, memory, uptime, connection freshness, and plain-language
next steps. Raw protocol data remains available in the Developer tab.

## What it can realistically do

| Capability | What the app knows | Important limitation |
| --- | --- | --- |
| Physical board view | Which squares currently contain a magnetic piece | Reed switches detect occupancy, not piece identity |
| Logical chess view | Expected piece type and legal position from `python-chess` | It can differ from reality after a missed or manual correction |
| App-controlled play | Tap every human source/target and let the mechanism execute both sides without reed input | Requires matching 5.0.1 firmware; every completed move needs visual confirmation and any uncertainty ends the game |
| Direct movement | Click one square for head-only motion, or an occupied source and empty destination for a magnet-carried piece | Direct carries must share a file, rank, or diagonal; requires matching 5.0.1 firmware, in-app calibration, fresh sensors, and e6 telemetry verification |
| Board alignment | Measure any two chosen squares one Cartesian step at a time and copy exact `global.h` values | Requires matching 5.0.1 firmware; changes take effect only after editing, rebuilding, uploading, and recalibrating |
| Collision-safe automatic routing | Windows can evacuate and restore blockers, stage the main piece, and recursively free trapped pieces | Version 5.0.1 always uses the verified transaction; bounded search can report that no verified plan was found |
| Carriage view | The Nano's calculated and persisted square | There is no encoder; missed motor steps cannot be measured directly |
| Magnet indicator | Whether firmware commanded the magnet on | There is no current sensor proving that the coil energized |
| Limits/buttons | Electrical input state and A6 analog value | A snapshot does not prove the switch is mechanically positioned correctly |
| Bluetooth monitoring | Local BLE telemetry, sensor snapshots, and reconnects | HC-08 BLE is short-range and does not provide internet access |
| Camera | Local USB webcam or RTSP/HTTP view | A camera can miss obstructions and is not a safety device |
| Remote halt | A dedicated `!` byte checked inside motion loops | Radio, Windows, or firmware failure can prevent delivery; use physical power |
| Strong chess | Stockfish 18 with adjustable Elo and thinking time | The Nano's standalone Micro-Max remains much weaker |

The app never automatically clears motion faults or assumes that a stale camera
view is safe. Calibration and automatic moves require deliberate controls. Safe
diagnostics never move the mechanism.

## Hardware wiring used by firmware 3.28+

```text
HC-08 TXD -- 1 kOhm -- service jumper -- Nano D10 (Bluetooth receive)

Nano D1/TX -- 1 kOhm --+-- HC-08 RXD
                       +-- 2 kOhm -- GND

HC-08 GND ----------------------------- Nano GND

Button B / black-limit signal --------- Nano A6
Nano A6 ------------------- 10 kOhm ---- Nano 5V
Button B / black-limit other terminal -- Nano GND
```

D0 remains exclusively connected to the Nano's onboard USB bridge. D11 remains
Button A / white limit. A6 requires the external pull-up because it is
analog-input-only. The HC-08 service jumper can remain closed during USB uploads.

Use Nano 5 V for HC-08 VCC only if the carrier board explicitly includes a 3.3 V
regulator and accepts 5 V input. A bare HC-08 requires regulated 3.3 V power.

## Reed-sensor coordinate wiring (firmware 3.31+)

The firmware is built for the glued-tile wiring used by this project. It
normalizes the raw multiplexer rank permutation and the sensor panel's 180-degree
orientation before standalone move recognition, capture handling, setup checks,
manual piece movement, and `BOARD` telemetry. Firmware 3.30 could therefore show
the opposite square—for example physical e6 as d3 and physical b2 as g7. Firmware
3.31 reports both as their physical chess coordinates. Do not compensate by
flipping only an app drawing, because the Nano also uses these coordinates for
chess and motion verification. A custom sensor panel with different wiring must
change this normalization at the firmware scan boundary.

## Install and run

Install Python 3.11 or newer, then open PowerShell in this directory:

```powershell
Set-ExecutionPolicy -Scope Process Bypass
.\setup.ps1
.\run.ps1
```

`setup.ps1` creates an isolated environment, installs the three required Python
packages, and invokes `install-stockfish.ps1` to download the official Stockfish
18 release separately. It does not install camera packages unless requested.

For a USB webcam, RTSP camera, or HTTP video stream:

```powershell
.\setup-camera.ps1
```

That command adds camera support to a source installation. Packaged users need
the camera-enabled release produced by `build.ps1 -IncludeCamera`; installing
packages beside the normal packaged executable cannot extend its embedded Python
runtime.

## First safe connection

1. Leave the mechanism clear and keep physical power accessible.
2. Select **BLE**, click **Scan**, choose the HC-08, and click **Connect**.
3. Open **Diagnostics** and run **Safe diagnostics**. These checks do not move.
4. Confirm telemetry reports both limit/button inputs released. A6 should normally
   read well above 700 and near 1023.
5. Use the Monitor tab to compare green physical sensor dots with logical pieces.
6. Test each physical limit input locally before requesting calibration.
7. Only then use **Play -> Start game and calibrate**.

The companion may also use USB or **Simulator**. Simulator mode is the recommended
starting point for contributors and UI demonstrations because it cannot energize
hardware. In the Developer tab, `SIMMOVE e2e4` simulates a human move.

## Interface guide

### Monitor

- Green dot: sensor occupancy agrees with the logical piece.
- Orange dot: a sensor sees a piece where the logical board expects none.
- Red outline: a logical piece is expected but its sensor is empty.
- Cyan target: the Nano's estimated carriage square.
- The right side translates firmware state into plain-language guidance.
- Live monitoring alternates `TELEM` and `BOARD` requests and permits only one
  outstanding poll, preventing a slow BLE link from building a command backlog.

### Play

Stockfish supplies legal moves and strength. Windows also
plans the complete physical rearrangement before an automatic move. It can park
blocking pieces temporarily, restore them, stage the main piece when it blocks a
return path, and recursively free a trapped blocker. Carried paths are
orthogonal, avoiding physically unsafe diagonal squeezing.

Firmware 5.0.1 removes continuous knight and unequal-ratio carry paths. The Play
planner still completes those chess moves by stopping on verified square
centres and issuing separate straight `DRAG` operations.

Choose **Verified reed switches** for the existing sensor-backed game. Choose
**Move by tapping app** for a board with missing or unreliable switches. The
latter requires the standard physical starting position, matching 5.0.1 firmware, and no
manual board movement except when the app explicitly prompts you to replace a
piece after promotion. Tap the source and destination on the Play board and the
mechanism performs the human move as well as the Stockfish reply. Both sides use
the full collision-safe planner. After every chess move the app previews the
result and asks the person at the board to confirm the complete physical
position. **No** stops the session; disconnect, halt, or route failure does the
same. This mode never treats virtual occupancy as proof that a piece was
actually carried.

In reed mode, before planning the app requires a fresh 64-square frame that exactly matches
the logical game. It then executes a transaction containing one straight drag at
a time and checks a fresh frame after each drag. A capture or disconnected move
that cannot be proved is treated as uncertain and stops the session; it is never
retried automatically. See [ARCHITECTURE.md](ARCHITECTURE.md) and
[REMOTE_SAFETY.md](REMOTE_SAFETY.md).

The Nano still owns sensor scanning, motor timing, calibration, magnet control,
physical limit checks, and either reed-derived or explicitly virtual per-drag
occupancy checks. Thinking and route search use Windows resources. Version 5.0.1
has no legacy direct-move fallback; mismatched app/firmware versions can inspect
state and halt, but cannot start control or motion.

### Diagnostics

The guided routine checks the connection, firmware identity, telemetry, all 64
sensors, control inputs, Stockfish, and optional camera dependencies. A support
bundle can then be saved for a GitHub issue.

### Board alignment

Use this separate tab only after ordinary commissioning and a successful app
calibration. Choose any square and start the recommended head-only session,
then nudge X/Y one step until the head is visually centered and record it.
Repeat at a far-away square with a different file and rank. The app reports the
four exact source coefficients to copy into `global.h`; it accounts for
`MOTOR_MICROSTEPS` and never changes firmware or EEPROM itself.

Magnetic-marker mode is optional and has an additional confirmation. It pulses
the magnet only during a nudge; head-only mode never energizes it. Finishing
reverses the measurement offset but intentionally leaves the carriage unhomed,
so upload/reconnect/power loss can never bypass calibration. Reconnect restores
an active measurement through `ALIGN STATUS`. Verify at least four separated
squares after rebuilding, uploading, and calibrating the new firmware.

### Camera

Enter `0` for the first local webcam, another integer for a different camera, or
an RTSP/HTTP URL. Video is displayed locally and is never recorded automatically.
Snapshots are created only when the user explicitly chooses **Save snapshot**.
URLs containing credentials are not persisted, and support bundles redact every
network-camera URL.

### Developer

The structured timeline and raw protocol view help developers at different
experience levels. Commands are classified before sending:

- Read-only diagnostics are immediately available.
- Session-control commands are identified clearly.
- Commands that can move hardware remain locked and require a second confirmation.
- Unknown commands are blocked.
- Emergency halt is always visible at the top of the application.

## Reconnection and stale state

BLE reconnect uses exponential backoff up to 15 seconds. USB retries every two
seconds. The monitor shows the age of the last board response and changes health
colour when data becomes delayed or stale. It never represents an old response as
live state.

The Nano blocks while producing precise motor steps, so normal telemetry may pause
during movement. The application stops polling while movement is expected. The
single-character emergency halt is handled separately inside the motion loops.

## Logs, privacy, and support bundles

Structured JSONL logs are stored under:

```text
%LOCALAPPDATA%\OpenAutomaticChessboard\logs
```

Support bundles contain the current firmware/telemetry snapshot, sanitized app
settings, the active session log, operating-system information, and public
protocol documentation. They exclude camera frames, PGNs, Stockfish binaries,
and stored camera credentials. Always inspect a ZIP before attaching it to a
public issue.

## Development and public releases

See [DEVELOPMENT.md](DEVELOPMENT.md), [ARCHITECTURE.md](ARCHITECTURE.md), and
[CONTRIBUTING.md](CONTRIBUTING.md). Run tests with:

```powershell
.\.venv\Scripts\python.exe -m unittest discover -s tests -v
```

Create a distributable Windows folder with:

```powershell
.\build.ps1
```

The build produces `dist\OpenAutomaticChessboard` and a versioned Windows ZIP.
Stockfish is deliberately not embedded; run the included
`install-stockfish.ps1` beside the packaged app or select an existing engine.
GitHub Actions runs the same unit-test and compile checks on Windows for every
companion change.

The default release excludes camera libraries. To create a larger camera-enabled
build with OpenCV and Pillow bundled, use `build.ps1 -IncludeCamera` and label
that release accordingly.

The companion is licensed under GNU GPL version 3 or later, matching its
`python-chess` rules dependency. Stockfish is GPLv3 and is downloaded separately
into the ignored `stockfish` directory. See `THIRD_PARTY_NOTICES.md`.

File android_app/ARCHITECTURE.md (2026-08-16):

# Android architecture

```text
HC-08 BLE / Simulator
          |
          v
 BoardTransport ---- LineBuffer, reconnect, 20-byte serialized writes
          |
          v
 BoardRepository --- one pending poll / exclusive route owner / typed state
       |        |
       |        +------ DiagnosticsRunner / SupportBundle
       v
 GameController ---- chesslib ---- StockfishEngine
       |
       +------ routing/RoutePlanner ---- bounded labeled configuration search
       |
       v
 MainActivity ------ fixed adaptive pages / ChessboardView / CameraController
```

## Boundaries

- `protocol` is dependency-free and owns wire parsing, board-bit ordering, line
  framing, route splitting, command generation, and command risk.
- `transport` owns Android Bluetooth details. It never interprets chess or board
  state. `SimulatorTransport` implements core firmware behaviour, including the
  complete `PLANROUTE` transaction.
- `BoardRepository` is the only connection/protocol authority. Ordinary
  read-only requests enter one deduplicating queue. It permits one outstanding
  read, alternates TELEM and BOARD, times out missing responses, resets across
  reconnects, and emits immutable `MonitorState` snapshots.
- During a route, `BoardRepository` grants exclusive ownership to
  `GameController`, clears queued polling, rejects unrelated commands, and sends
  only the coordinator's next verified command. The emergency `!` path remains
  available.
- `GameController` owns logical chess state, engine sequencing, immutable route
  planning jobs, stale-generation rejection, transaction acknowledgements,
  timeouts, expected occupancy, and uncertain-state recovery.
- `domain/routing` is pure Kotlin with no Android dependency. It owns the labeled
  rearrangement model and is JVM unit-tested independently.
- `StockfishEngine` is a narrow UCI adapter. It serializes engine access, clamps
  Elo/time, bounds waits, validates returned UCI, and closes its process.
- `ui` renders state and collects deliberate intent. It does not parse protocol
  lines or access Bluetooth GATT.
- `camera` owns only live preview and explicit snapshots. Camera state is
  observational, never an interlock or automatic recorder.

## Routing model

One macro action carries one labeled piece through empty four-connected squares.
Orthogonal-only planning conservatively satisfies the board's diagonal clearance
rule. Exact labeled goals turn evacuation/restoration, main-piece staging, and
recursive clearing into one configuration search.

The planner uses iterative temporary-piece budgets and focused, broad, then
bounded exhaustive successor generation. Candidate corridors minimize blockers;
parking ranks reserved goals, articulation points, distance, mobility, turns,
and deterministic square order. The physical cost prioritizes:

1. number of distinct secondary pieces disturbed;
2. actual magnet pickups after turns are split;
3. carried distance;
4. turns.

Hardware-validated side-adjacent pieces do not add a penalty to an otherwise
empty orthogonal route.

Search duration, node count, temporary pieces, corridor/parking branch width,
and dependency depth are bounded. An exact structural classifier distinguishes
proven impossibility from bounded-search failure. For the normal one-primary
move shape, a deterministic dense-board constructor supplies a reversible,
replay-validated incumbent. It may replace a completed bounded-search result
when its lexicographic objective is better, or be returned if bounded
optimization cannot finish; it is marked non-optimal. Optional exact macro A*
supports small developer cases. No unverified move is ever returned. Captures,
en passant, promotion occupancy, and both standard castling sides are adapted
before search. Capture removal is a search transition containing a tracked
carried path to any available `a1`-`a8` exit. A winding empty route requires no temporary
piece movement; only a genuinely disconnected edge invokes ordinary recursive
parking. Version 5.0.1 has no legacy routing branch.

## Route transaction

The phone requires a fresh sensor frame equal to chesslib's occupancy. Planning
runs on the existing named worker against an immutable problem. A generation
counter discards results after stop, disconnect, or position change.

Execution is strictly:

```text
PLAN -> BOARD -> (straight DRAG -> BOARD)* -> [capture DRAG(s) -> BOARD -> REMOVE -> BOARD] ->
        (straight DRAG -> BOARD)* -> COMMIT
```

Each exact acknowledgement advances one state. The phone maintains the expected
occupancy independently from the Nano and uses separate control and physical-
motion timeouts. `PLAN` never moves hardware; `REMOVE` is sent only after
the planner has routed the capture to a valid exit. After `REMOVE` or any `DRAG`, loss of
proof makes state uncertain. The app sends one `STOP`, releases the connection
owner, ends the game, and requires inspection instead of retry.

Reed switches prove occupancy, not identity, gantry position, magnet current, or
piece centring. The host owns chess legality and labels; the Nano owns
deterministic motion, limits, magnet cutoff, corridor checks, and sensor-frame
proof.

The protocol also supports explicit `APPBOARD` authority. The user selects every
human move in `ChessboardView`; `GameController` sends both sides through the
same route transaction. The Nano maintains a separate command-derived virtual
frame and `BOARD` returns that frame during the session, so phone/Nano state is
still cross-checked after each command without consulting unreliable reeds.
After `DONE`, the snapshot previews the proposed logical result and a
non-cancelable whole-board confirmation blocks progression. Mismatch or
disconnect stops and invalidates the game. There is deliberately no automatic
fallback between reed and virtual authority.

## Threading and lifecycle

BLE callbacks are converted into repository events. UI observers always run on
the main looper. Polling and Stockfish/route planning use named single-thread
executors. Camera2 uses one handler thread. Route timeout callbacks carry a token
so stale callbacks cannot affect a newer move. Transport, camera, game engine,
poll executor, pending scan, and callbacks are closed from the activity
lifecycle; an active route is stopped before the repository is closed.

The app reconnects only to a user-selected saved address. A scan does not
auto-connect to a similarly named nearby device. The HC-08's 9600-baud link is
protected by a single pending request, exclusive transaction owner, and 20-byte
write queue. Diagnostics waits for its complete serialized response batch.
Structured log writes use one daemon writer and bounded rollover files.

## State authority and safety invariants

1. chesslib owns legal position and piece identity.
2. In verified mode, BOARD owns physical occupancy after firmware rank
   normalization. In explicitly selected APPBOARD mode it owns the Nano's
   command-derived virtual occupancy and must never be presented as sensor proof.
3. TELEM reports commanded/calculated mechanism state, not physical proof.
4. A timestamp older than 12 seconds is stale, never ready, except while expected
   motion deliberately suppresses polling; that state is reported as a warning.
5. Movement-capable developer commands require an unlock and confirmation.
6. Unknown commands and raw route-transaction commands are blocked.
7. `!` is unframed and available independently of normal newline commands.
8. No UI path remotely clears a motion fault.
9. Ordinary polling pauses for calibration, automatic movement, and routes.
10. Diagnostics contains read-only protocol commands only.
11. `ManualControl` owns square selection and verification. Movement remains
    disabled until `CALIBRATED e6` agrees with fresh homed, fault-free,
    magnet-off telemetry; piece moves additionally require fresh occupancy.

## Extending the protocol

Add a typed value and parser in `protocol`, simulator coverage, repository event
reduction, parser/model tests, then display it. Bump the coordinated software
version and update Nano, Android, and Windows in the same release. Host-planned
motion must retain exclusive ownership and exact acknowledgement checks.

## Fixed-layout rule

All six pages divide the available window with weights after applying status and
navigation bar insets. Do not introduce `ScrollView`, `RecyclerView`, or
horizontal scrolling. Add pagination or a focused fixed-size dialog when data
can grow. Test at 320dp-wide portrait and short landscape sizes with large
system font before merging UI changes.

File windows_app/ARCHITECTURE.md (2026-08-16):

# Companion architecture

```text
HC-08 BLE / USB / Simulator
             |
      transports.py  (reconnect, framing, 20-byte BLE writes)
             |
      main-thread event queue
             |
   +---------+----------+----------------+
   |                    |                |
protocol.py        MonitorModel      routing.py
parse/version      health/mismatch   labeled rearrangement search
   |                    |                |
   +--------------------+----------------+
                        |
                    Tkinter UI
                        |
             +----------+-----------+
             |                      |
        EventRecorder          CameraWorker
        JSONL/support ZIP      optional local frames
```

## Responsibility boundary

The Windows host owns expensive or evolving policy: chess legality, Stockfish,
labeled-piece configuration search, evacuation/restore ordering, main-piece
staging, time/node budgets, and transaction orchestration. The Nano owns the
small deterministic safety kernel: sensor scanning, homing, limit checks, step
timing, magnet cutoff, straight-corridor validation, per-drag occupancy proof,
and final-frame proof.

This separation keeps the Nano maintainable and makes future planners replaceable
without weakening the hardware guardrails. Version 5.0 has one route-transaction
contract and no direct-move fallback. An exact `HELLO 5.0.1` handshake gates all
control and motion commands.

## Routing model

`routing.py` models a labeled configuration of physical pieces. Only one piece
moves at a time. Carried paths use the four orthogonal neighbours; this is a
conservative subset of the physical diagonal-clearance rule and therefore never
attempts to squeeze diagonally between pieces.

The bounded best-first search can:

- route the primary piece directly;
- evacuate blockers to empty parking squares and restore them;
- stage the primary piece while a blocker returns through a shared gate;
- recursively move secondary blockers to free a trapped piece;
- handle capture removal, en passant, promotion occupancy, and both standard
  castling sides.

Capture removal is itself a bounded search transition. The captured piece
becomes a tracked transaction
object: Windows routes it through empty square centres to any available `a1`-
`a8` exit using ordinary verified `DRAG`s, then sends `REMOVE`. A zero-disturbance
path therefore wins even when it winds around occupied squares. Only when every
edge exit is disconnected does the normal dependency/parking search move another
piece. There is no version-dependent routing branch in the 5.0 companion.

Candidate corridors and parking squares are ranked before full configuration
search. Disturbance count dominates the cost, followed by the physical number of
magnet pickups, carried distance, and turns. Side-adjacent pieces do not add a
penalty to an otherwise empty orthogonal route. Time, node,
temporary-piece, corridor, parking, and dependency-depth limits bound worst-case
optimization work. An exact structural classifier distinguishes proven
impossibility from a bounded-search failure. For the normal one-primary move
shape, a deterministic dense-board constructor builds a reversible incumbent
before search; it is returned only when preferable or when bounded search fails,
and only after full replay validation. Such a result is explicitly non-optimal.
Optional exact macro A* is available to development tools for small cases. The
app never substitutes an unverified physical move.

A logical path may turn, but `protocol.py` splits it into maximal straight runs.
The magnet releases and reacquires only at square centres. This lets every
`DRAG` have a simple corridor proof and a complete post-move sensor proof.

## Transaction orchestration

Before planning, Windows requests a fresh 64-square `BOARD` frame and requires
exact agreement with the logical position. Planning runs on a worker thread
against an immutable board copy. Generation identifiers discard results made
stale by disconnect, stop, or a newer move.

Execution is one command at a time:

```text
PLAN -> BOARD -> (DRAG -> BOARD)* -> [capture DRAG(s) -> BOARD -> REMOVE -> BOARD] ->
        (DRAG -> BOARD)* -> COMMIT
```

Windows waits for the exact acknowledgement, maintains its own expected
occupancy frame, and applies separate control and motion timeouts. The Nano also
checks the authoritative occupancy frame locally. `PLAN` is motionless;
after any `REMOVE` or drag, a lost or mismatched acknowledgement makes physical
state uncertain and ends the session instead of retrying.

`APPBOARD` provides an explicit second authority mode rather than weakening that
proof opportunistically. In `APPBOARD` play, both human and AI moves originate
in the UI. The Nano seeds and independently updates a virtual standard-position
occupancy frame; `BOARD` exposes that command-derived frame so the existing
transaction comparison remains intact without sampling reed inputs. After
`DONE`, Windows previews the intended result and blocks all further moves until
the user visually confirms the whole physical board. A mismatch sends `STOP` on
a best-effort basis while transport remains available. After connection loss,
Windows invalidates the logical session without claiming that `STOP` was
delivered. Both cases require physical inspection and recalibration through the
established recovery procedure. Code must never auto-switch authority based on
sensor quality.

## Threading

Tkinter is touched only by the main thread. USB, BLE, Stockfish thinking, route
planning, camera capture, discovery, and engine diagnostics run in worker
threads and communicate through a queue. Transport callbacks may run on any
worker and must remain small.

All ordinary read-only requests pass through one main-thread queue. Exactly one
request may await its matching response at a time; a timeout releases the next
request. Route transactions temporarily own the command channel and normal
polling pauses until they finish or fail.

## State authority

- `python-chess` is authoritative for legal rules and expected piece identity.
- Reed sensors are authoritative only for physical occupancy in verified mode.
- In explicitly selected `APPBOARD` play, command-derived Nano/app occupancy is
  authoritative for routing while human visual confirmation is the only
  physical feedback.
- The Nano normalizes raw multiplexer rows through the fixed hardware row map
  before move logic or `BOARD` telemetry consumes them.
- Nano telemetry reports commanded/calculated controller state.
- The visual model displays disagreement instead of silently choosing one source.
- `ManualSelection` owns direct-control mode and square selection. The UI enables
  movement only after e6 calibration agrees with fresh telemetry, while both
  app and firmware enforce source/destination occupancy.

## Extensibility

Protocol evolution uses coordinated release versions. Change the shared version,
firmware, both companions, typed parsers, simulators, diagnostics, documentation,
and tests together. Parsers reject malformed data without taking control action;
there is no legacy motion fallback.

## Safety design

Read-only and motion commands are classified in `protocol.py`. The Developer UI
locks motion commands, unknown commands are blocked, ordinary polling pauses
while motion is expected, and support tooling is read-only. The `!` emergency
path is separate from newline parsing and checked inside Nano motor loops.
Settings are replaced atomically, and only the 20 most recent structured log
sessions are retained.

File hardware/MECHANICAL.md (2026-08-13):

# Mechanical interface

The frame is intentionally adaptable. The tested build reuses 3D-printer
V-slot extrusion, V-wheels, belts, pulleys, and motors, but the firmware needs
only the following measurable interfaces.

## Required geometry

- Playing field: 300 x 300 mm.
- Square pitch: 37.5 mm in both axes.
- Eight square centers must form a repeatable 37.5 mm grid.
- The carriage must reach every square center, the calibration switches, the
  e6 park location, and the left-side capture release path without collision.
- The mechanism must resist racking and belt slip over repeated diagonal
  moves. Both axes must remain square to the playing field.

The mechanism measures about 195 full motor steps across the nominal 37.5 mm
square pitch. Release firmware intentionally commands a 190-step logical pitch
and recenters the e6 calibration park, keeping every outer square about 3.3 to
3.5 mm inside the measured travel boundary so the carriage cannot contact the
frame. The prototype's 297 mm tile assembly is offset relative to its
calibration hardware, so its file axis is additionally translated about
6.5 mm toward the white switch/a-files. This places the 24 mm magnet under the
h-file tiles instead of against their outer edge. The safety inset and field
translation are motion calibration values, not universal CoreXY geometry. If
pulley tooth count, belt pitch, motor step angle, microstepping, carriage
geometry, board placement, or available clearance changes, measure and update
`FILE_PITCH_STEPS`, `RANK_PITCH_STEPS`, the two
`CALIBRATION_PARK_*_STEPS` values, and
`MOTOR_MICROSTEPS` before normal play.

## Confirmed donor-printer rail set

The tested build and the matching donor set use five pieces of 20 x 20 mm
V-slot extrusion. The lengths below were confirmed from the physical set; they
replace the earlier approximate ranges in this guide. They are independently
documented here as a cut list rather than reproducing the reference photograph.

| Qty | Rail function | Finished length |
| ---: | --- | ---: |
| 2 | Left and right side frame rails | **345 mm each** |
| 1 | Long frame cross rail | **350 mm** |
| 1 | Short frame cross rail | **315 mm** |
| 1 | Moving gantry rail | **395 mm** |

The compact procurement notation is `2 x 345 + 1 x 350 + 1 x 315 + 1 x 395
mm`. Label the pieces before assembly; the 395 mm gantry is intentionally the
longest rail and should not be confused with an outer cross rail.

The current public build recommendation follows this donor hardware and the
repository's 3D model rather than the exact dimensions of the base
Instructables frame.

| Interface | Recommended starting point | What must be verified |
| --- | --- | --- |
| Outer frame | Two 345 mm side rails, one 350 mm cross rail, and one 315 mm cross rail | Equal diagonals, 300 mm board clearance, bracket and endstop allowance |
| Moving gantry | One 395 mm rail | Full square-center reach and clearance from both outer rails |
| Linear guidance | Eight mini V-wheels, four eccentric spacers, four fixed spacers, and matching shims | No play, no bearing roughness, and free travel without preload binding |
| Drive | Two 20-tooth GT2 pulleys with 5 mm motor bores | Shaft fit, set-screw engagement, and agreement with motion calibration |
| Belt | Two CoreXY paths using 2 mm-pitch, 6 mm-wide GT2 belt; allow about 4 m total | Belt condition, parallel belt planes, independent tension, and no frame bowing |
| Idlers | Up to eight 6 mm-belt idlers on verified M5 stacks | Smooth surface against belt back; toothed surface against belt teeth; no flange rub |
| Frame joints | Approximately 8-10 right-angle brackets and about 30 matching M5 T-nuts | Squareness and resistance to racking under diagonal motion |

The detailed starter fastener assortment is in `BOM.md`. Exact axle screw
length depends on the printed bracket, pulley width, washers, shims, spacer,
and locknut. A screw must fully engage the locknut without bottoming in a motor
or protruding into a belt path.

Salvaged parts should be cleaned and inspected individually. Replace a V-wheel
with a flat spot, an idler with bearing play, a belt with damaged teeth, a motor
with an intermittent lead, or any fastener whose drive recess no longer accepts
full tightening torque.

## Printed alternatives

The `printFiles` directory includes separately attributed models for a 20 x
20 mm V-slot profile and compatible corner brackets. They are options for
experimentation, not evidence that printed plastic is structurally equivalent
to aluminium. A printed rail or bracket must pass the same squareness, racking,
repeatability, temperature, and endurance checks as donor aluminium hardware.
Layer orientation, creep, fastener compression, and bearing-surface wear must
be considered before using a printed component in the moving frame. Printed
rail replacements must preserve the 20 x 20 mm cross-section and reproduce the
five longitudinal lengths above. If a printer cannot make a rail in one piece,
the segment joints need positive alignment and reinforcement; glue-only butt
joints are not suitable for wheel-bearing or belt loads.

## Enclosure, sliding chassis, and board support

The working mechanism is built as a removable internal body that slides into
the outer case from the front. Four TPU spacers attach at the front and rear of
that body. They center it, restrain movement, support the enclosure/chassis
interface, and reduce vibration. Fit them with light, even compression: the
body must not rattle, but it must remain removable without bending the frame or
dragging cables through the case.

The tested case was printed with a 0.8 mm nozzle, three perimeters, and a slicer
extrusion-width limit of about 0.82 mm, giving a nominal 2.4 mm wall, top, and
floor. These settings describe the prototype rather than imposing one printer
profile. A substitute case must remain flat, keep the board and chassis
supported, and preserve access to the cutoff, fuses, USB connector, driver
adjusters, and removable harnesses.

The prototype's 2.2 mm tiles are glued to a repurposed 3D-printer glass door.
Because the glass is about as thick as the 2.4 mm case top, stacking the glass
board on an intact top would add a second structural layer to the magnetic
pickup path. The prototype instead supports the glass in an opening cut into
the printed case, lowering the playing surface while keeping it rigid.

A builder who attaches the tiles and supported reed switches directly to the
case top does not need that opening: the case top replaces the glass layer.
Whichever method is used, support the complete 300 x 300 mm field against
tilting and flex, protect glass edges, retain the board against sliding, and
test pickup plus sensing with every piece on every square. Never cut or drill a
glass plate unless its manufacturer explicitly permits that operation.

See the [working prototype photographs](PROTOTYPE.md) for the sliding body,
TPU spacer function, glass recess, and current enclosure print settings.

## Reed tile requirements

- Place one normally-open reed switch at each logical square.
- The prototype leaves about 0.2 mm between the switch and the magnet-equipped
  piece. A different tile may use a larger gap only after every piece is tested
  on every square.
- Provide a slot or pocket that supports the switch body. Never bend a lead
  directly where it exits the glass capsule.
- Add strain relief before gluing. Hot glue may hold the cable and switch, but
  it must not preload or twist the glass.
- Route sensor wires away from motor, magnet, and belt movement. Label every
  cable with square and multiplexer/channel before the top is closed.
- Confirm that the H2520 carriage magnet does not falsely close neighboring
  reed switches through the board. The Windows visual monitor should be used
  to observe occupancy while moving the unpowered carriage by hand.

## Carriage and magnet

- Mount the H2520 magnet face parallel to the board underside.
- Use mechanical fasteners or a retained bracket; adhesive alone must not be
  the only thing preventing the magnet from falling into the belts.
- Keep a consistent air gap across the full travel. A tilted board produces
  weak pickup in one area and collisions in another.
- Provide cable flex relief so the magnet wire cannot catch a pulley or pull
  on the TIP120 connection.
- Verify that a piece releases reliably after the firmware's magnet-off dwell.
  Residual magnetism, excessive friction, or a sticky tile surface can make an
  electrically correct machine fail mechanically.

## Calibration switches

The two normally-open switches are also the two front-panel buttons outside
calibration. Mount them so the carriage actuates them before any hard stop, and
so a failed switch does not let the carriage eject a belt or crush wiring.

The current calibration sequence seeks the firmware's white switch first and
then the black switch. Because the exact donor-motor sides are not yet labelled,
do not infer switch identity from wire color or physical left/right position.
Use `COMMISSIONING.md` to identify and label `D11 / SWITCH_A` and
`A6 / SWITCH_B` before enabling homing.

## Acceptance tests for a custom frame

Before carrying a chess piece, the frame should pass all of these:

- Full travel by hand with power removed, with no binding or wire snagging.
- Both switches change state before a mechanical hard stop.
- Ten unloaded moves to each corner with no belt skip or pulley loosening.
- Repeated return to one marked square within 1 mm.
- A 15-minute unloaded motion test with no connector, driver, motor, or wire
  becoming unusually hot.
- Sensor view remains stable while the carriage moves with the electromagnet
  off.

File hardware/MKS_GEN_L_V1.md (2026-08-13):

# MKS Gen L V1.0 complete build profile

This is the supported ATmega2560 alternative to the classic Nano controller.
It fits both CoreXY drivers, the 64 reed switches through the existing four
16-channel multiplexers, both calibration/button switches, the 16x2 I2C LCD,
the HC-08 Bluetooth module, and the 24 V electromagnet on one board.

This profile is specifically for the board marked **MKS Gen_L V1.0**. Do not
apply it to an MKS Gen L V2.x or a generic Mega/RAMPS board by appearance.
Connector names and pin numbers below were checked against Makerbase's official
V1.0_008 pin drawing, schematic, and BOM.

## Orientation

Place the board as shown in the official pin drawing: the five driver sockets
form the top row in the order `X Y Z E0 E1`; the `12/24V` input and HE/FAN
outputs are at the left; the colored endstop, servo, AUX, and thermistor headers
are at the right/bottom. Printed `+`, `-`, `S`, `G`, `V`, and pin labels on the
actual board are authoritative.

The machine-readable version of every external connection is
[`mks-gen-l-v1-connections.csv`](mks-gen-l-v1-connections.csv).

MKS Gen L V1.0 chessboard wiring overview

## One-page connection map

| Function | MKS connector/contact | Firmware pin | Connect to |
| --- | --- | ---: | --- |
| CoreXY motor `WHITE` | X motor output | X STEP 54, DIR 55, EN 38 | Motor 1 coil pairs |
| CoreXY motor `BLACK` | Y motor output | Y STEP 60, DIR 61, EN 56 | Motor 2 coil pairs |
| Electromagnet | HE0 `+` / `-` | D10 | Magnet `+` / `-`, diode across magnet |
| Switch A / white limit | X- `S` / `G` | D3 | Normally-open switch |
| Switch B / black limit | Y- `S` / `G` | D14 | Normally-open switch |
| MUX shared signal | SERVOS2 D4 / GND | D4 | All four `SIG` pins / ground |
| MUX address `S0-S3` | AUX-2 pins 4,3,6,8 | A9,A5,D40,D42 | All four MUX modules |
| MUX enables `EN0-EN3` | AUX-2 pins 10,5,7,9 | A11,A10,D44,A12 | One enable per MUX |
| MUX power | AUX-2 pin 2 / pin 1 | 5V / GND | All four MUX modules |
| LCD SDA / SCL | SERVOS1 D11 / D6 | D11 / D6 | I2C backpack SDA / SCL |
| LCD power | SERVOS1 5V / GND | 5V / GND | I2C backpack VCC / GND |
| Bluetooth replies | AUX-1 TX / D1 | D1 TX0 | Divider to HC-08 RXD |
| Bluetooth commands | EXP1 pin 3 | D17 RX2 | HC-08 TXD |
| Bluetooth power | AUX-1 5V / GND | 5V / GND | 5V-rated HC-08 carrier |

`WHITE` and `BLACK` are inherited motor identifiers, not wire colors or chess
sides. Never infer a coil pair from wire color. With the motor disconnected,
find the two low-resistance pairs with a meter. One pair occupies `1A/1B`; the
other occupies `2A/2B`. Never unplug a motor while its driver is powered.

## Driver installation and full-step jumpers

1. Remove USB and 24 V. Confirm the X and Y driver sockets are unpowered.
2. Install only tested A4988 or DRV8825 carriers in X and Y, matching `EN`,
   `STEP`, `DIR`, `GND`, and motor-supply orientation to the board labels. A
   reversed carrier can be destroyed immediately. Other carrier families are
   unsupported until their pinout, full-step configuration, and geometry are
   validated with this profile.
3. For the release geometry and speed, leave all three X and Y microstep jumper
   positions **open** for full-step operation. If jumper caps are currently
   fitted beneath the sockets, remove them before inserting the drivers.
4. Fit heatsinks without touching header pins. Provide forced air.
5. Set VREF for each particular carrier and motor. The prior prototype values
   are not universal: A4988 and DRV8825 formulas differ, and clone sense
   resistors differ.

The profile drives both onboard enable pins safely: HIGH while STEP/DIR are
initialized, then LOW continuously. That preserves motor holding and the
calibrated CoreXY position.

## Electromagnet on HE0

HE0 already contains a logic-level low-side MOSFET and reset-state gate bias,
so this profile does **not** use the external TIP120, 1 kohm base resistor, or
10 kohm base pull-down.

```text
HE0 +  -> electromagnet +
HE0 -  -> electromagnet -

flyback diode directly across the magnet:
stripe/cathode -> magnet + / HE0 +
plain/anode    -> magnet - / HE0 -
```

The external flyback diode remains mandatory. The board schematic shows only
the output indicator path and MOSFET body diode; neither is a flyback diode
across the load. The documented H2520 is 24 V, 2.8 W (about 117 mA), well below
the normal current of a hot-end output, but verify the actual coil current and
inspect connector/MOSFET temperature during commissioning. The official BOM
identifies the HE outputs' switch part as VS3060AD.

Feed protected 24 V to the board's `12/24V +` and `GND` screw terminal through
the same external fuse, latching hardware cutoff, and reverse-polarity stage as
the Nano design. Leave H-BED, HE1, FAN, Z, E0, and E1 unused. USB can power the
logic for motionless tests, but it cannot power the motors or electromagnet.

## Reed-switch system

The individual glass reed switches do **not** connect directly to 64 Mega
pins. Keep the four existing 16-channel multiplexers:

```text
each reed: one terminal -> its documented C0..C15 channel
           other terminal -> GND

all MUX: S0,S1,S2,S3 shared
         SIG shared
         VCC shared at 5V
         GND shared
         EN separate
```

The square/channel mapping is unchanged: use [`sensor-map.csv`](sensor-map.csv).
MUX0 is a2-h2/a1-h1, MUX1 is a8-h8/a7-h7, MUX2 is a6-h6/a5-h5, and MUX3 is
a4-h4/a3-h3. The unusual order matches the physical prototype and firmware.

AUX-2 is a 2x5 header. Use the pin numbers printed in Makerbase's drawing, not
left/right guesses:

| AUX-2 pin | Signal | Wire to |
| ---: | --- | --- |
| 1 | GND | all MUX GND |
| 2 | 5V | all MUX VCC |
| 3 | A5 / D59 | all S1 |
| 4 | A9 / D63 | all S0 |
| 5 | A10 / D64 | MUX1 EN |
| 6 | D40 | all S2 |
| 7 | D44 | MUX2 EN |
| 8 | D42 | all S3 |
| 9 | A12 / D66 | MUX3 EN |
| 10 | A11 / D65 | MUX0 EN |

SERVOS2 `D4` receives all four MUX `SIG` pins; use the GND contact in that same
three-pin group. Do not use TH1, TH2, or TB for sensor data. Makerbase fits each
thermistor input with a 4.7 kohm / 10 uF low-pass filter, which is intentionally
slow for temperature measurement and incompatible with a rapid 64-channel scan.

On the official drawing the two adjacent three-pin groups are:

```text
SERVOS2: D4  5V  GND   <- shared MUX SIG uses D4 and GND
          D5  5V  GND
SERVOS1: D6  5V  GND   <- LCD SCL uses D6
         D11  5V  GND  <- LCD SDA uses D11; LCD power may use this row
```

## LCD and Bluetooth

The V1.0 board does not expose ATmega2560 hardware SDA/SCL on a connector.
Firmware therefore runs the existing PCF8574/MCP23008 LCD backpack on a
software-I2C bus:

```text
SERVOS1 D11 -> LCD SDA
SERVOS1 D6  -> LCD SCL
SERVOS1 5V  -> LCD VCC
SERVOS1 GND -> LCD GND
```

Bluetooth is full duplex and independent of USB receive:

```text
HC-08 TXD ------------------------> EXP1 pin 3 (D17 / RX2)

AUX-1 TX (D1) -> 1 kohm ->+------> HC-08 RXD
                           |
                         2 kohm
                           |
                          GND

AUX-1 5V/GND -> HC-08 carrier VCC/GND
```

The divider keeps the HC-08 RX input near 3.3 V. Direct HC-08 TXD to D17 is
correct: a 3.3 V output is a valid HIGH for this 5 V AVR input. Supply 5 V only
to a carrier board with its own regulator; a bare radio module requires 3.3 V.

EXP1 numbering follows the keyed 2x5 connector: pin 1 is `D37`, pin 2 is `D35`,
pin 3 is `D17`, and pin 10 is `5V`. Use only pin 3 for HC-08 TXD; do not rotate
an IDC plug or feed 5 V into the radio TX output.

## Build and upload

Install pinned dependencies and compile both profiles:

```powershell
./firmware/test.ps1 -InstallDependencies
```

With 24 V physically disconnected, upload the MKS image explicitly:

```powershell
./firmware/build.ps1 -HardwareProfile mks-gen-l-v1 -Upload -Port COM11
```

The build reports `MKS_GEN_L_V1` in `INFO`; a generic Mega compile is not a
substitute. Nano remains the default build when `-HardwareProfile` is omitted.

## Safe commissioning order

1. **Bare board, USB only:** no drivers, motors, magnet, MUX, LCD, or Bluetooth.
   Upload the MKS profile and run the motionless serial probe. `TELEM` must show
   magnet `0`; `INFO` must include `MKS_GEN_L_V1`.
2. **Logic loads, USB only:** connect LCD, MUX modules, reeds, switches, and
   Bluetooth. Confirm the LCD, `BOARD`, Bluetooth, and `SWTEST`. Validate all 64
   squares with one piece magnet. No 24 V yet.
3. **Drivers fitted, 24 V off:** verify carrier orientation, full-step jumper
   state, coil pairs, VREF, heatsinks, fan, flyback diode, fuse, and cutoff.
4. **One motor at a time, magnet disconnected:** enable protected 24 V and use
   only `JOG W+/-`, then only `JOG B+/-`. Keep a hand on the hardware cutoff.
   Correct direction by reversing one complete coil pair, never by mixing pairs.
5. **CoreXY without pieces/magnet:** connect both motors, calibrate, run straight
   horizontal/vertical head moves at the release speed, and check for collision,
   resonance, step loss, belt slip, and driver temperature.
6. **Magnet only:** disconnect motors or remove their VMOT path; connect the
   electromagnet and prove off-state, short pulse, release, 30-second firmware
   cutoff, diode orientation, and MOSFET/connector temperature.
7. **Integrated board:** reconnect motion and magnet, calibrate, verify e6 at
   calibration completion, test app/USB/Bluetooth head moves, then test one
   carried piece before a populated board.

After any collision, missed step, driver reset, motor disconnect, emergency
cutoff, or manual carriage movement, calibration is mandatory. USB/Bluetooth
`!` is best effort; the external hardware cutoff remains the real safety stop.

## Official board references

- [Makerbase MKS Gen L repository](https://github.com/makerbase-mks/MKS-GEN_L)
- [Official V1 pin drawing](https://github.com/makerbase-mks/MKS-GEN_L/blob/master/hardware/MKS%20Gen_L%20V1.0_008/MKS%20Gen_L%20V1.0_008%20PIN.pdf)
- [Official V1 schematic](https://github.com/makerbase-mks/MKS-GEN_L/blob/master/hardware/MKS%20Gen_L%20V1.0_008/MKS%20Gen_L%20V1.0_008%20SCH.pdf)
- [Official V1 BOM](https://github.com/makerbase-mks/MKS-GEN_L/blob/master/hardware/MKS%20Gen_L%20V1.0_008/MKS%20Gen_L%20V1.0_008%20BOM.pdf)

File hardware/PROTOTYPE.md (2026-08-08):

# Working prototype reference

These photographs show the current working machine during enclosure and wiring
development. The mechanism, sensor board, controller PCB, Bluetooth link, LCD,
and electromagnet operate; exposed wiring and open covers in these views are
service-access states, not a recommended finished enclosure.

The photographs were supplied by project author Roni Tervo in 2026 and are
covered by the repository's [CC BY-NC-SA 4.0 license](../LICENSE.md). The
repository copies were exported at their original pixel dimensions with
location and device metadata removed; the source photographs were not changed.

## Overall arrangement

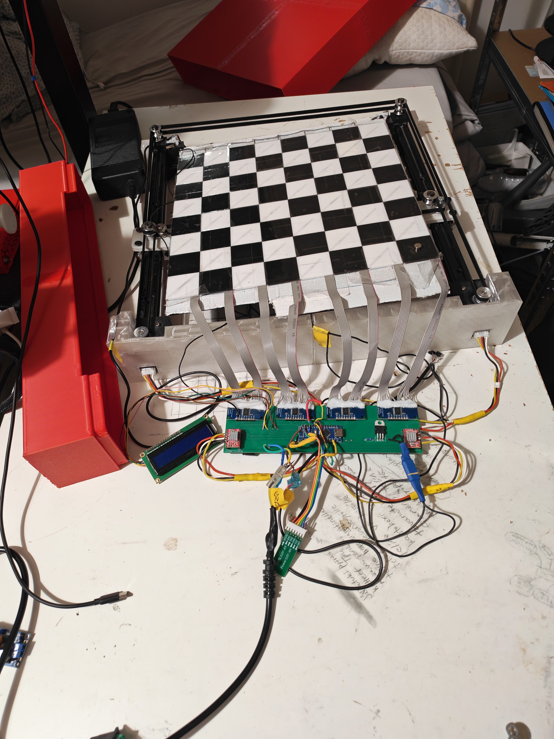
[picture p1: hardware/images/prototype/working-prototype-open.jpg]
Working automatic-chessboard prototype with the board and controller exposed


The complete motion mechanism forms an internal body, or chassis, that slides
into the outer case from the front. This keeps the mechanism removable for
belt, wheel, magnet, sensor, and controller service instead of permanently
trapping it inside the enclosure.

Four project-authored TPU spacers attach to the front and rear of the internal
body. They are functional parts rather than cosmetic trim:

- they center the body inside the case;
- restrain side-to-side and vertical movement;
- add support between the chassis and enclosure; and
- reduce transmitted vibration and rattling.

The spacers should provide light, even restraint without requiring force to
insert or remove the chassis. Recheck the fit after the TPU has been compressed
for several days, and keep cables clear of every sliding contact surface.

## Board support and pickup distance

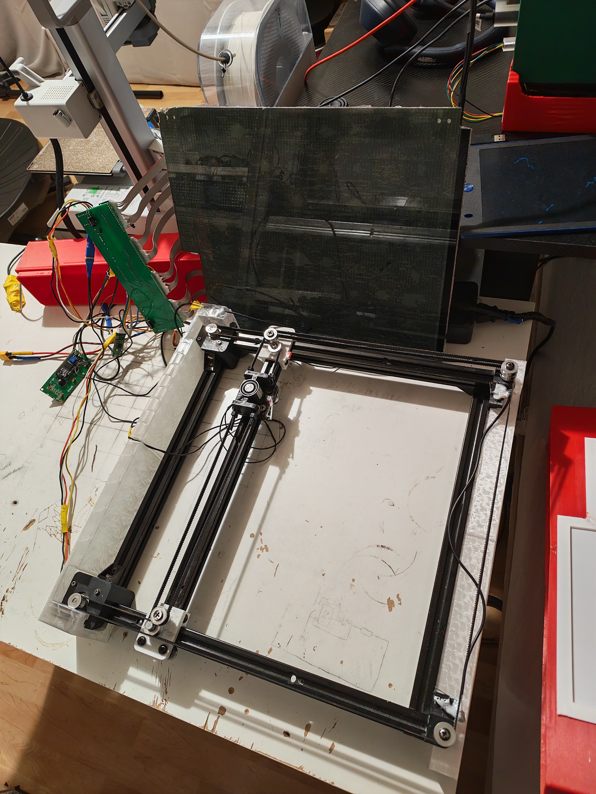
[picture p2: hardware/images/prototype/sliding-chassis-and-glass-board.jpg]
Motion chassis with the repurposed printer glass board raised for access


The prototype's 2.2 mm printed tiles are glued to a repurposed 3D-printer glass
door, with the reed switches supported in the tile pockets. The glass is about
the same thickness as the enclosure's 2.4 mm top skin. Placing this complete
glass-and-tile assembly on top of an unmodified enclosure would add the top
skin to the magnetic path and make the H2520 electromagnet too weak for
reliable pickup.

The prototype therefore uses a large opening cut in the printed case top. The
glass is lowered into that opening and supported solidly around it, so the case
top and glass do not form two stacked structural layers below the playing
surface.

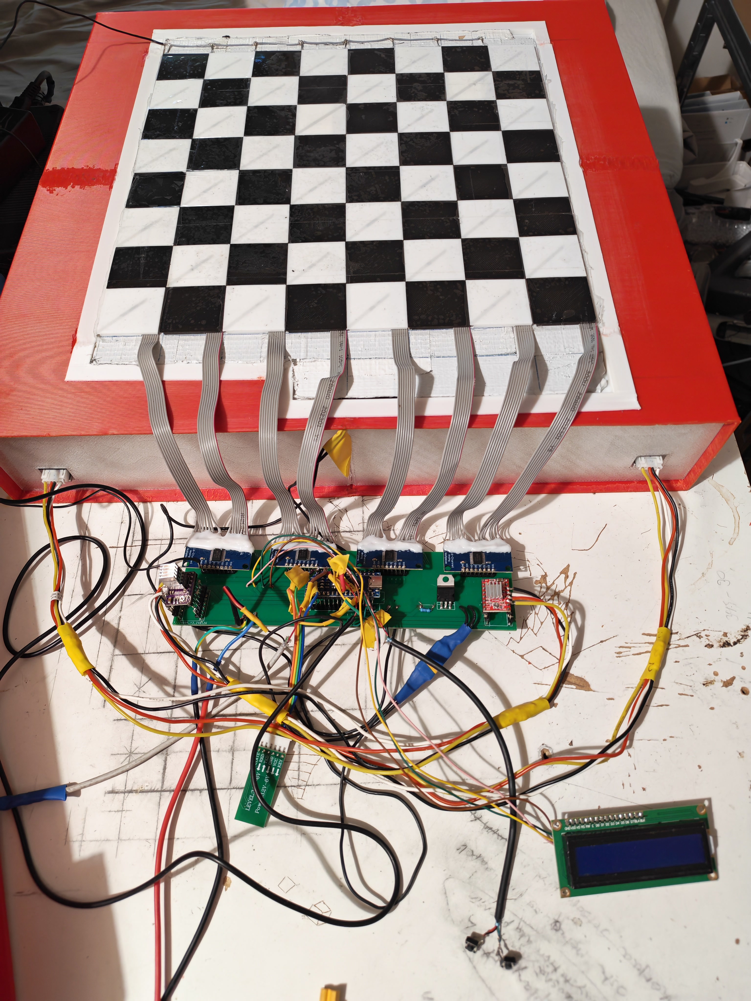
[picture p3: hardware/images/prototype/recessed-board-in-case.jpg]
Glass-backed tile board recessed into the red outer case


Two top constructions are supported by this design:

1. **Recessed glass board:** cut an opening in the printed case, provide a
   level ledge or distributed supports, and retain the glass against sliding or
   lifting. Protect every glass edge and do not drill, trim, or point-load a
   glass plate whose tempering and machining limits are unknown.
2. **Tiles directly on the case:** attach the tiles and their supported sensor
   harness directly to the case top. The top skin then replaces the glass in
   the magnetic path, so no large opening is required.

Either construction must remain flat, keep every reed switch protected, and
hold a consistent distance between the carriage electromagnet and all 32 piece
magnets. Validate every finished piece on every square before closing the case;
nominal layer thickness alone cannot prove reliable sensing or pickup.

## Tested enclosure print

The supplied enclosure STL was printed with a 0.8 mm nozzle and three
perimeters. The slicer limited extrusion width to about 0.82 mm, producing a
nominal 2.4 mm wall, top, and floor around the case. These are tested prototype
settings, not mandatory slicer requirements. A different nozzle, wall count,
material, or infill is acceptable if the result remains flat, supports the
board safely, retains the sliding chassis, and leaves the mechanism serviceable.

Additional cosmetic covers may hide the controller and wiring, but they must
not obstruct the physical cutoff, ventilation, USB access, fuses, driver
adjusters, removable connectors, or the front removal path.

### Finishing the enclosure

The next enclosure iteration can look cleaner without sacrificing the current
service access. Prefer removable screwed or clipped panels over permanently
glued covers, and include:

- a guarded controller bay that prevents fingers or loose chess pieces from
  reaching exposed terminals;
- cable guides and strain relief for the eight sensor ribbons, motor leads,
  magnet lead, display, switches, and Bluetooth module;
- direct access to the cutoff, fuse holders, USB connector, display, and player
  controls;
- ventilation around the buck converter, motor drivers, and their heatsinks;
  and
- keyed connectors or sufficient service loops so the internal body can slide
  out without cutting or desoldering wires.

Before accepting a new cover, repeat full carriage travel by hand and confirm
that no panel, fastener, cable, or service loop enters the belt or trolley
envelope.

## Working PCB and external rework

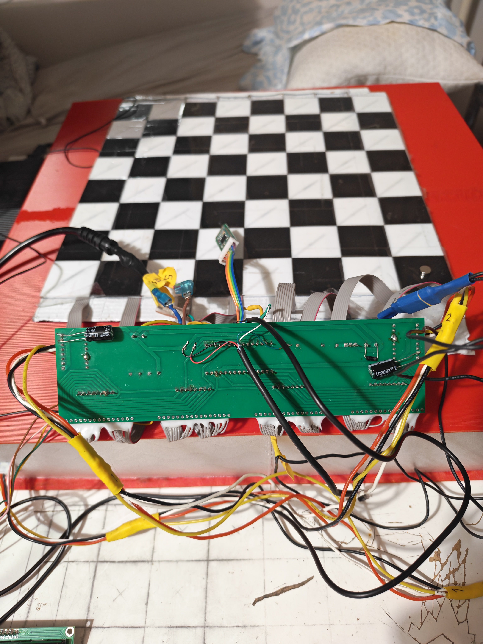
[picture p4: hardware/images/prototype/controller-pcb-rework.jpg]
Back of the working long controller PCB showing external patch wiring


The fabricated long controller PCB is functional and is used by the working
prototype. Its archived KiCad design predates several current connections, so
the assembled board works only with external wires and resistors that implement
the current [wiring contract](WIRING.md):

- do not use the legacy D10 switch connector for the second switch;
- connect HC-08 `TXD` through 1 kohm to Nano `D10`;
- move the second normally-open switch to Nano `A6`, with the other switch
  terminal at GND and a 10 kohm pull-up from `A6` to 5 V;
- connect Nano `D1/TX` through 1 kohm to HC-08 `RXD`, with 2 kohm from that
  divider node to GND; and
- add every other external connection required by
  [`connections.csv`](connections.csv), rather than assuming an unrouted PCB
  net is optional.

This proves that an existing fabricated board can be reused and repaired. It
does not turn the historical KiCad files into a fabrication release: they do
not contain all current routing, protection, Bluetooth, A6, or verified
manufacturing details. See the
[`legacy-controller` notice](reference/legacy-controller/README.md) before
working on one.

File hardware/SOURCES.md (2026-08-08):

# Component references

## Design lineage

This hardware is a modified implementation of Greg06's
[Automated Chessboard](https://www.instructables.com/Automated-Chessboard/).
That project provides the high-level CoreXY, magnetic-piece, reed-sensor, and
multiplexer architecture. Its page is marked
[CC BY-NC-SA 4.0](https://creativecommons.org/licenses/by-nc-sa/4.0/).

The BOM, wiring tables, safety additions, measured dimensions, and assembly
instructions in this repository describe the current 24 V donor-printer build
and are independently written. The base project's fixed rail cuts, 12 V power
arrangement, separate arcade buttons and limit switches, and exact component
shopping list are not specifications for this version. See the repository
[`ATTRIBUTION.md`](../ATTRIBUTION.md) for a change summary.

## Electrical references

These primary sources define electrical behavior. Marketplace listings are
kept only in `BOM.md` to identify the tested form factor; a seller may change a
product without changing its title.

- [Arduino Nano hardware page](https://docs.arduino.cc/hardware/nano/)
- [Arduino Nano classic pinout](https://docs.arduino.cc/resources/pinouts/A000005-full-pinout.pdf)
- [Allegro A4988 datasheet](https://www.allegromicro.com/-/media/files/datasheets/a4988-datasheet.ashx)
- [Pololu A4988 carrier application notes](https://www.pololu.com/product/1182)
- [TI CD74HC4067 product page and datasheet](https://www.ti.com/product/CD74HC4067)
- [onsemi TIP120 datasheet](https://www.onsemi.com/pdf/datasheet/tip120-d.pdf)
- [JGMaker official A3S product page](https://www.jgmaker3d.com/products/a3s)

The current procurement options shown by the interactive explorer are examples
chosen to satisfy these requirements. They are not the source of the firmware
pin contract and do not override a manufacturer datasheet.

The fitted driver is marked HR4988SQ rather than Allegro A4988. A mirrored
manufacturer datasheet identifies the same `Itrip = VREF / (8 x Rsense)`
relationship, but builders should still treat the carrier's chip and resistor
markings as part-specific:

- [YONGFUKANG HR4988SQ datasheet mirror](https://www.alldatasheet.com/datasheet-pdf/pdf/1132086/YONGFUKANG/HR4988SQ.html)

The official A3S page lists printer-level specifications but no motor model,
phase current, winding resistance, or torque. No authoritative electrical
specification was found for the unlabelled donor motors, so this guide does not
claim one. The measured working system uses R100 carriers at 0.720 V.

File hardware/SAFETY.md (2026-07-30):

# Safety rules

This machine combines a 24 V supply, stored energy in motors and capacitors,
an electromagnet, glass switches, and a moving belt carriage. Read this page
before assembling or troubleshooting it.

## Non-negotiable protections

The public design requires all of the following:

- Use an enclosed, regulated 24 V DC supply. Do not build or expose mains-side
  wiring as part of this project.
- Put a **3 A time-delay fuse rated for at least 32 V DC** in the 24 V positive
  lead, as close to the power inlet as practical. This is the conservative
  starting value for the documented load. Use wiring that can safely carry the
  fuse rating; 0.75 mm2 / 18 AWG copper is recommended for the main 24 V path.
- Put a **latching physical cutoff rated for at least 30 V DC and 5 A** after
  the fuse. It must remove power from the drivers, magnet, and logic buck and
  must be reachable without crossing the mechanism.
- Add reverse-polarity protection rated for at least 30 V DC and 5 A. Use a
  properly rated ideal-diode/MOSFET module or series Schottky solution; verify
  its input and output polarity before connecting the board.
- Enclose or guard live terminals, the moving belts, and pinch points. Add
  strain relief where power and motor cables enter the mechanism.
- Keep the device supervised while powered. Keep loose metal, magnetic media,
  and people with magnet-sensitive medical devices away from the carriage.

Measure the 24 V input current during the longest loaded motion. If normal
operation approaches 3 A, calculate a replacement from the measured maximum
input current and the safe current of the smallest wire. **5 A is the maximum
allowed by this guide's recommended wiring**, not an automatic upgrade. Never
increase a fuse simply because it opens; first find the cause.

## Rules that prevent common driver failures

- Never plug, unplug, or rearrange a stepper motor while 24 V is present.
- Never insert a StepStick carrier backwards. Compare `VMOT`, `GND`, `VDD`,
  `1A`, `1B`, `2A`, and `2B` labels before applying power; carrier colors are
  not a pinout standard.
- Mount one 100 uF, 50 V electrolytic directly across `VMOT` and motor `GND`
  at each driver. The negative stripe goes to GND.
- Set the current limit before sustained motor testing. A4988-compatible
  carriers differ in chip, sense-resistor value, and VREF scaling.
- Keep the heatsink electrically clear of pins and solder joints. Stop testing
  if the driver, connector, wire, motor, or capacitor becomes unusually hot,
  smells, discolors, or behaves intermittently.
- Do not use a resistance measurement from the VREF screw to ground to infer
  motor current. Measure powered VREF and identify both sense resistors.

## 5 V and USB rule

The documented buck produces regulated 5.0 V, so connect it to the Nano `5V`
pin. The classic Nano pinout specifies `VIN` for 7-12 V input; feeding 5 V into
`VIN` loses voltage in the onboard regulator and can undervolt the controller.

Classic Nano clones do not all isolate USB 5 V from an externally driven 5 V
rail in the same way. The beginner-safe rule is:

1. Switch off and disconnect the 24 V supply before attaching USB.
2. Verify that the external 5 V rail is at 0 V.
3. Upload or diagnose over USB.
4. Disconnect USB before restoring external power.

If simultaneous USB data and external power are required, use a verified cable
or adapter that keeps D+ and D- connected while disconnecting USB VBUS, or use
a documented power-OR/isolator design. Ordinary "data blocker" adapters do the
opposite and are not suitable. Do not cut or modify an unidentified cable while
it is connected to a computer.

## Safe migration of an existing 5 V-to-VIN build

For the current prototype:

1. Disconnect the 24 V supply and USB. Wait at least 60 seconds.
2. Measure between the 24 V and GND rails; confirm there is no voltage.
3. Disconnect the buck output from Nano `VIN`.
4. With the Nano still disconnected, power only the buck input and adjust its
   output to **5.00 V**. Accept 4.90-5.10 V; target 5.00 V.
5. Remove power again and confirm 0 V.
6. Connect buck `OUT+` to Nano `5V` and `OUT-` to common GND.
7. Run the logic-only stage in `COMMISSIONING.md` before reconnecting 24 V
   loads.

Do not connect 24 V to `VIN`, `5V`, any logic module, or any Nano I/O pin.

## First movement

- Raise or remove the playing surface so the carriage is visible.
- Remove chess pieces, tools, and loose wires.
- Keep one hand next to the physical cutoff, not inside the mechanism.
- Use the Windows app's read-only diagnostics first. Connecting and polling
  must not move the carriage.
- Calibration intentionally moves hardware. Start it only after both limit
  inputs have been tested by hand and the travel directions are known.

Software halt commands are useful for controlled stopping, but BLE can
disconnect and a controller can crash. Use the physical cutoff for unexpected
motion.

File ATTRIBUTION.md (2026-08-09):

# Design lineage and attribution

## Base project

This repository is a modified implementation of
[**Automated Chessboard**](https://www.instructables.com/Automated-Chessboard/)
by Instructables user
[**Greg06**](https://www.instructables.com/member/Greg06), licensed under
[CC BY-NC-SA 4.0](https://creativecommons.org/licenses/by-nc-sa/4.0/).

The base project established the overall arrangement used here: a CoreXY-style
mechanism below a magnetic chessboard, an Arduino Nano, two STEP/DIR motor
drivers, an electromagnet switched through a transistor and flyback diode, 64
normally-open reed switches read through four 16-channel multiplexers, an I2C
display, two player controls, and a compact Micro-Max chess engine.

The current documentation was written for this repository from prototype
measurements, current firmware behavior, and component datasheets. It does not
reproduce the source project's prose, diagrams, or photographs.

## Material changes in this implementation

This is not a drop-in reproduction of the base build. Important changes
include:

- a 300 x 300 mm playing field with 37.5 mm square pitch;
- reused JGAurora A3S printer motors, V-slot rails, V-wheels, GT2 belt,
  pulleys, idlers, and frame hardware instead of a fixed purchased frame kit;
- a 24 V H2520 electromagnet and 24 V motor rail instead of the base project's
  12 V power arrangement;
- HR4988SQ StepStick-compatible carriers with measured `R100` sense resistors,
  full-step operation, and prototype-specific current calibration;
- protected power distribution with a main fuse, latching cutoff,
  reverse-polarity protection, local driver capacitors, and a regulated 5 V
  buck feeding the Nano `5V` pin;
- two controls that also serve as calibration endstops, including an external
  pull-up for the Nano's analog-only A6 pin;
- an HC-08 BLE interface and a versioned monitoring/control protocol;
- a different LCD library with automatic PCF8574-backpack detection;
- a measured sensor-channel permutation matching the assembled board;
- persistent position journaling, guarded calibration, service diagnostics,
  step-loss testing, capture-bin routing, and revised carried-piece paths;
- separate GPL-licensed Windows and Android monitoring/Stockfish companions; and
- project-specific enclosure, tile, and TPU spacer models plus separately
  attributed third-party printable components.

## Micro-Max

The compact chess engine was written by **H. G. Muller**. The local
`Micro_Max.cpp` remains recognizably derived from the version included with the
base project. Upstream information is available from the
[Micro-Max author page](https://home.hccnet.nl/h.g.muller/max-src2.html).
The licensing qualification in [`LICENSE.md`](LICENSE.md) applies.

## Third-party 3D models

The original archives, source links, authors, modification statements, and
licenses for imported models are kept beside each package under
[`hardware/printFiles/third_party`](hardware/printFiles/third_party/). The
index in [`hardware/printFiles/README.md`](hardware/printFiles/README.md)
summarizes them.

No attribution implies endorsement by Greg06, H. G. Muller, Thingiverse, or
any third-party model creator.

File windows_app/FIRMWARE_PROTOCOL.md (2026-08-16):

# Firmware protocol 5.0.1

The Nano uses newline-terminated printable ASCII at 9600 baud over USB and the
HC-08 transparent BLE link. Version 5.0.1 is one coordinated firmware/companion
contract; it does not negotiate old capability sets or fall back to old motion
commands.

## Exact release handshake

Each transport must establish its own match before sending a control or motion
command:

```text
> HELLO 5.0.1
< HELLO 5.0.1
> INFO
< INFO ACB3 5.0.1 NANO
```

The MKS build reports `MKS_GEN_L_V1`; simulators report `SIM`. A different `HELLO`
version returns `ERR VERSION` and clears that transport's agreement. `INFO`,
`TELEM`, and `BOARD` remain readable before agreement. `STOP` and the byte-level
`!` emergency halt also remain available so a mismatched tool can make a
best-effort stop and inspect state, but it cannot control or move the board.
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

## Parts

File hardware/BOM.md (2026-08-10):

# Bill of materials

This BOM is for the modified 24 V prototype documented in this repository, not
for a literal reproduction of the base Instructables build. The prototype
reuses motion hardware from a dismantled JGAurora A3S printer. Equivalent donor
parts are acceptable when they meet the measurable requirements below.

The [machine-readable BOM](bom.csv) separates required specifications from the
tested or recommended reference. Seller titles, colors, and connector shapes
are not specifications; verify markings, dimensions, pin labels, voltage
ratings, and motor coil pairs before assembly.

## Controller, sensing, and interface

| Qty | Part | Required specification | Tested or recommended reference |
| ---: | --- | --- | --- |
| 1 | Arduino Nano | Classic ATmega328P, 5 V, 16 MHz | Nano-compatible USB-C clone in the prototype; [official classic Nano](https://docs.arduino.cc/hardware/nano/) is the reference |
| 1 | USB data cable | Fits the selected Nano and carries data, not charge-only | Match the clone's USB connector |
| 4 | 16-channel multiplexer breakout | CD74HC4067-compatible, 5 V logic, active-low enable, labelled `SIG/S0-S3/EN/VCC/GND` | WAVGAT CD74HC4067 module ([listing](https://www.aliexpress.com/item/32848578672.html)) |
| 64 | Reed switch | Normally open glass reed that closes reliably through the selected tile and piece-magnet gap | Littelfuse MDSR-4-class part or equivalent; prototype switches are glued into printed tile slots |
| 1 | 16x2 I2C LCD | 5 V HD44780 display with a supported PCF8574-family backpack | Common blue 1602 module such as this [1602 backpack assembly](https://www.addicore.com/products/1602-16x2-character-lcd-with-i2c-backpack); firmware auto-detects the backpack rather than requiring address `0x27` |
| 2 | Combination button/endstop | Normally open lever or roller microswitch, accessible to the player and actuated by the carriage before a hard stop | One shared control/endstop per calibration direction; [Omron D2F-01L](https://www.digikey.fi/en/products/detail/omron-electronics-inc-emc-div/D2F-01L/83262) is a reproducible switch option |
| 1 | A6 pull-up | 10 kohm, 1/4 W | Installed between A6 and 5 V inside heat-shrink |
| 1 | BLE module | HC-08 BLE UART carrier that accepts a 5 V supply; UART remains 3.3 V logic | HC-08 carrier such as [DSD TECH SH-HC-08](https://www.deshide.com/product-details_1663307.html); optional when USB-only operation is sufficient |
| 2 | BLE series/divider resistor | 1 kohm, 1/4 W | One in TXD-to-D10 and one in D1-to-RXD divider |
| 1 | BLE divider resistor | 2 kohm, 1/4 W | HC-08 RXD node to GND |

Do not substitute a Nano Every, Nano R4, 3.3 V Nano, or unrelated
multiplexer without reviewing firmware timing, A6 behavior, voltage levels,
memory use, and pinout.

## Motion and electromagnet electronics

| Qty | Part | Required specification | Tested or recommended reference |
| ---: | --- | --- | --- |
| 2 | Stepper driver carrier | A4988/HR4988 StepStick pinout, 24 V capable, adjustable current limit | HR4988SQ red carrier with two `R100` sense resistors; [Pololu A4988 Black Edition](https://www.pololu.com/product/2128) is a documented substitute whose own sense resistance must be used |
| 2 | Driver heatsink | Electrically isolated from pins and sized for the carrier | Adhesive aluminium StepStick heatsink |
| 2 | Stepper motor | Four-wire bipolar NEMA 17, 1.8 degree preferred, at least 0.20 N m holding torque; rated phase current must match the configured limit | Unlabelled JGAurora A3S donor motors; [17HS13-0404S1](https://www.omc-stepperonline.com/nema-17-bipolar-1-8deg-26ncm-36-8oz-in-0-4a-12v-42x42x34mm-4-wires-17hs13-0404s1) is a purchasable 0.26 N m, 0.4 A/phase option |
| 2 | Driver capacitor | 100 uF, at least 50 V, electrolytic, 105 C preferred, mounted directly at `VMOT`/GND | 100 uF 50 V low-impedance radial capacitor such as [Panasonic EEU-FR1H101](https://www.digikey.fi/en/products/detail/panasonic-electronic-components/EEU-FR1H101/3561182) |
| 4 | STEP/DIR pull-down resistor | 10 kohm, 1/4 W; one independent resistor from each driver `STEP` and `DIR` input to logic GND | Four 10 kohm resistors installed and tested on the working prototype |
| 1 | Electromagnet | 24 V DC, approximately 2.8 W, 25 mm diameter x 20 mm high or mechanically compatible | [H2520 24 V / 2.8 W](https://zslanda.en.made-in-china.com/product/rtypxJCcOURO/China-Landa-H2520-Round-Holding-Electromagnet-100n-25mm-Diameter-20mm-Height-24V-12V-DC-Cast-Iron-Mini-Magn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) |
| 1 | Magnet switch transistor | TIP120 NPN Darlington, or a separately validated logic-level N-MOSFET circuit | [onsemi TIP120G](https://www.digikey.fi/en/products/detail/onsemi/TIP120G/920293), no heatsink required at the prototype's approximately 117 mA nominal load |
| 1 | Flyback diode | At least 1 A and 50 V; reverse-connected across the magnet during normal operation | 1N4004 through 1N4007; stripe toward +24 V |
| 1 | Base resistor | 1 kohm, 1/4 W | Nano D6 to TIP120 base |
| 1 | Base pull-down | 10 kohm, 1/4 W | Added between TIP120 base and GND for a defined off state during reset |

The driver current limit is set from the motor's rated phase current and the
actual carrier sense resistors. The prototype's 0.720 V reference is valid only
for its `R100` carriers and donor motors; it is not a universal A4988 setting.

## Power and protection

| Qty | Part | Minimum requirement | Tested or recommended reference |
| ---: | --- | --- | --- |
| 1 | 24 V DC supply | Enclosed, regulated, isolated; 3 A minimum, 5 A recommended | Prototype uses an unbranded 24 V 10 A brick, allowed only with the documented fuse; [Mean Well GST90A24-P1M](https://www.meanwell-web.com/content/files/pdfs/productPdfs/MW/GST90A/GST90A-spec.pdf) is a reproducible enclosed option |
| 1 | Buck converter | 24 V input, regulated 5.0 V output, at least 1 A continuous; 36 V-or-higher input and 2 A output rating recommended | Adjustable prototype buck; [Pololu D24V25F5](https://www.pololu.com/product/2850) is a fixed 5 V option |
| 1 | Main fuse and holder | 3 A time-delay starting value, at least 32 V DC, close to the inlet | Covered inline or panel holder |
| 1 | Latching cutoff | Normally closed power path, reachable, at least 30 V DC and 5 A | Two-pole emergency-stop or latching power switch |
| 1 | Reverse-polarity stage | At least 30 V DC and 5 A continuous | Rated ideal-diode/MOSFET module such as the [Pololu 4-75 V reverse protector](https://www.pololu.com/product/5358), or an engineered Schottky solution |
| 1 | Power distribution block | Covered, keyed or clearly polarized, rated above the main fuse | Separate protected +24 V and GND distribution |
| 1 | Logic fuse | 1 A, at least 32 V DC, on the buck input or suitably rated output | Inline holder or fused distribution position |
| as needed | Main power wire | 0.75 mm2 / 18 AWG copper recommended | Red/black stranded copper |
| as needed | Motor and branch wire | 0.34 mm2 / 22 AWG copper recommended | Stranded donor harness wire is acceptable after inspection |
| as needed | Logic and sensor wire | 0.14-0.25 mm2 / 26-24 AWG copper, strain-relieved | Ribbon cable and flexible hookup wire |
| as needed | Insulation and strain relief | Heat-shrink, cable ties/mounts, terminal covers, grommets, and ferrules for screw terminals | Select for the actual enclosure and cable exits |

## Interconnect and controller construction

| Qty | Part | Requirement or suggested starting quantity |
| ---: | --- | --- |
| 1 | Controller board | Rework the existing fabricated long PCB as documented, use 2.54 mm plated perfboard, or make a purpose-built board that implements `connections.csv`; the archived KiCad files are not a current fabrication release |
| as needed | 2.54 mm female headers | Socket the Nano and both StepStick carriers so their labels and orientation remain inspectable |
| as needed | Locking low-voltage connectors | One connector per motor, switch, magnet, display, BLE module, and removable sensor bank; current rating must suit the circuit |
| as needed | Screw terminals | Covered terminals rated above the circuit voltage and current for power branches and any non-locking removable wiring |
| 8 banks | Sensor harness | Eight square signals plus a common return per eight-square bank; label both ends with squares and MUX channels |
| as needed | Solder and assembly consumables | Electronics-grade solder, flux, heat-shrink, ferrules/crimps, standoffs, and nonconductive mounting hardware |

Breadboards and loose Dupont jumpers are suitable for logic-only experiments,
not for the finished moving 24 V machine.

## Donor-printer motion hardware

The following is the confirmed cut list for the current 300 mm board and the
matching donor-rail set. These are finished extrusion lengths, not approximate
frame dimensions. The prototype uses salvaged 3D-printer parts, so still check
that a substitute bracket and wheel stack matches this geometry before cutting
new material or ordering exact screw lengths.

| Qty | Part | Requirement or recommended option |
| ---: | --- | --- |
| 2 | Side frame rail | 20 x 20 mm V-slot aluminium, **345 mm finished length each** |
| 1 | Long frame cross rail | 20 x 20 mm V-slot aluminium, **350 mm finished length** |
| 1 | Short frame cross rail | 20 x 20 mm V-slot aluminium, **315 mm finished length** |
| 1 | Moving gantry rail | 20 x 20 mm V-slot aluminium, **395 mm finished length**; this is the rail carried by the outer motion system |
| 8 | Mini V-wheel | Matches the selected V-slot profile; no flat spots or bearing play |
| 4 | Eccentric spacer | M5, compatible with the wheel plate; used to remove play without binding |
| 4 | Fixed wheel spacer | 5 mm ID, approximately 6 mm high, matching the wheel stack |
| 8 | Precision shim | Approximately 8 mm OD x 5 mm ID x 1 mm, one per V-wheel where required by the donor stack |
| 8 | M5 locking nut | Nyloc or equivalent for wheel axles |
| 2 | GT2 drive pulley | 20 teeth, 2 mm pitch, 6 mm belt width, 5 mm motor bore, dual set screws preferred |
| up to 8 | GT2 idler pulley | Sized for 6 mm belt and the selected M5 axle stack; use smooth idlers against the belt back and toothed idlers where the tooth side bends |
| about 4 m | GT2 timing belt | 2 mm pitch, 6 mm wide, glass-fibre or steel reinforced; enough for both CoreXY paths plus tensioning allowance |
| 8-10 | 90-degree frame bracket | For 20 x 20 extrusion; aluminium or the separately attributed printable bracket after load testing |
| about 30 | M5 T-nut | Matches the extrusion slot; include spares before closing rail ends |
| assorted | M5 screws | Start with M5 x 8/10/12 mm for brackets and M5 x 20/25/30/35 mm for wheels and idlers; confirm every stack before tightening |
| 8 | M3 motor screw | M3 x 8-10 mm, or the depth required by the donor NEMA 17 motor without bottoming in the motor |
| as needed | M2/M3 printed-part hardware | Screws, washers, and locknuts sized to the switch, electronics, magnet, and printed support holes |
| 1 set | Belt anchors/tensioners | Secure both belt ends without sharp bends or tooth damage and permit independent tension adjustment |

The optional printable V-slot profile and corner-bracket packages are indexed
under [`printFiles`](printFiles/README.md). When making printed replacements,
produce the same five finished lengths: `345, 345, 350, 315, and 395 mm`. Do
not uniformly scale a profile to change its length, because that would also
change the 20 x 20 mm cross-section. Extend, trim, or segment it only along its
long axis. Printed plastic is not assumed to match aluminium stiffness, wear
resistance, or dimensional stability.

## Board, pieces, and printed parts

| Qty | Part | Requirement or recommended option |
| ---: | --- | --- |
| 64 | Printed board tile | 37.5 mm pitch with a protected reed-switch pocket and repeatable top height |
| 1 | Enclosure/frame interface | Supports a flat 300 x 300 mm playing field while preserving access to cutoff and service points |
| 4 | TPU frame spacer | Use the project-authored left/right front/back spacer models where they match the built case |
| 1 set | Chess pieces | Bases must accept magnets and slide reliably without scratching or catching tile joints |
| 32 | Piece magnet | [5 x 2 mm neodymium disc](https://www.supermagnete.fi/disc-magnets-neodymium/disc-magnet-5mm-2mm_S-05-02-N) is the current recommended starting point; use consistent pole orientation and validate every piece on every square |
| as needed | Low-friction base material | Thin felt or equivalent after confirming the added gap still closes every reed switch |
| as needed | Adhesive and cable retention | Compatible with tile, magnet, and wire materials; adhesive must not be the sole magnet-carriage safety retention |

Do not purchase the source project's exact rail cuts, button arrangement,
12 V electromagnet, or power supply for this build. This firmware and wiring
contract describe a different 24 V prototype with shared button/endstops and
project-specific geometry.

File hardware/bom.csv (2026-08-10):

category | quantity | item | minimum_specification | tested_reference | status
controller | 1 | Arduino Nano | Classic ATmega328P, 5V, 16MHz | Nano-compatible USB-C clone | required
controller | 1 | USB data cable | Connector matches selected Nano and cable carries data | USB-C data cable for prototype clone | required for programming
sensors | 4 | 16-channel multiplexer breakout | CD74HC4067-compatible, 5V, active-low enable | WAVGAT CD74HC4067 breakout | required
sensors | 64 | Normally-open glass reed switch | Closes reliably through selected tile and piece gap | Glass reed in printed tile slot | required
interface | 1 | 16x2 I2C LCD | 5V HD44780 LCD with supported PCF8574-family backpack | Blue 16x2 module with auto-detected backpack | required
interface | 2 | Normally-open combination button/endstop | Actuated by player and before carriage hard stop | Shared button and limit switch | required
interface | 1 | A6 pull-up resistor | 10kohm 0.25W | Inside heat-shrink | required
bluetooth | 1 | HC-08 BLE UART carrier | Carrier accepts 5V supply and uses 3.3V UART logic | HC-08 carrier | optional for USB-only build
bluetooth | 2 | 1kohm resistor | 0.25W | Inside heat-shrink | required for BLE
bluetooth | 1 | 2kohm resistor | 0.25W | Inside heat-shrink | required for BLE
motion | 2 | Stepper driver carrier | A4988 or HR4988 StepStick pinout and 24V capable | HR4988SQ with two R100 resistors | required
motion | 2 | Stepper-driver heatsink | Electrically clear of carrier pins | Adhesive aluminium StepStick heatsink | required
motion | 2 | Bipolar stepper motor | 4-wire NEMA17, 1.8deg preferred, >=0.20Nm, current matched to driver | Unlabelled JGAurora A3S donor motor | required
motion | 2 | VMOT capacitor | 100uF >=50V electrolytic 105C preferred | 100uF 50V | required
motion | 4 | STEP/DIR pull-down resistor | 10kohm 0.25W one per STEP and DIR input | Four 10kohm resistors tested on prototype | required
magnet | 1 | Electromagnet | 24V DC approximately 2.8W and mechanically compatible | H2520 24V 2.8W | required
magnet | 1 | NPN Darlington or validated MOSFET circuit | TIP120 or validated logic-level MOSFET alternative | TIP120 | required
magnet | 1 | Flyback diode | 1A >=50V axial diode | 1N4004-1N4007 equivalent | required
magnet | 1 | Base resistor | 1kohm 0.25W | 1kohm | required
magnet | 1 | Base pull-down resistor | 10kohm 0.25W | None on prototype | safety addition
power | 1 | 24V DC supply | Enclosed regulated isolated 3A minimum 5A recommended | Unbranded 24V 10A brick | required
power | 1 | Buck converter | 24V input, 5.0V output, >=1A continuous, >=36V input recommended | Unlabelled adjustable buck | required
protection | 1 | Main fuse and holder | 3A time-delay starting value >=32VDC | None on prototype | safety addition
protection | 1 | Latching cutoff | >=30VDC 5A and reachable | None on prototype | safety addition
protection | 1 | Reverse-polarity protection | >=30VDC 5A | None on prototype | safety addition
protection | 1 | Logic fuse | 1A >=32VDC | None on prototype | safety addition
protection | 1 | Covered power distribution | Rated above main fuse | Prototype solder distribution | required
wiring | as needed | Main power wire | 0.75mm2 or 18AWG copper recommended | Mixed prototype wire | required
wiring | as needed | Branch and motor wire | 0.34mm2 or 22AWG copper recommended | Mixed prototype wire | required
wiring | as needed | Logic and sensor wire | 0.14-0.25mm2 or 26-24AWG, strain-relieved | Ribbon and hookup wire | required
wiring | 1 | Controller board | Existing long PCB with documented external rework, 2.54mm perfboard, or purpose-built board implementing connections.csv | Working reworked long PCB | required
wiring | as needed | Female headers | 2.54mm sockets for removable Nano and StepStick carriers | Prototype socket headers | recommended
wiring | as needed | Locking low-voltage connectors | Voltage and current rated for each removable branch | Mixed donor connectors | recommended
wiring | as needed | Screw terminals | Covered and rated above circuit voltage and current | Mixed prototype terminals | recommended
wiring | 8 banks | Sensor harness | Eight square signals plus common return, labelled at both ends | Ribbon and hookup wire | required
mechanical | 2 | Side frame rail | 20x20mm V-slot, 345mm finished length each | Salvaged JGAurora A3S extrusion | required
mechanical | 1 | Long frame cross rail | 20x20mm V-slot, 350mm finished length | Salvaged JGAurora A3S extrusion | required
mechanical | 1 | Short frame cross rail | 20x20mm V-slot, 315mm finished length | Salvaged JGAurora A3S extrusion | required
mechanical | 1 | Moving gantry rail | 20x20mm V-slot, 395mm finished length and compatible with outer motion system | Salvaged JGAurora A3S extrusion | required
mechanical | 8 | Mini V-wheel | Matches selected V-slot with sound bearings | Salvaged printer V-wheels | required
mechanical | 4 | M5 eccentric spacer | Compatible with wheel plate | Salvaged printer spacer | required
mechanical | 4 | Fixed wheel spacer | 5mm ID, approximately 6mm high | Salvaged printer spacer | required
mechanical | 8 | Wheel shim | Approximately 8mm OD, 5mm ID, 1mm thick | Salvaged printer shim | as required by wheel stack
mechanical | 8 | M5 locking nut | Retains V-wheel axle | Salvaged nyloc nut | required
mechanical | 2 | GT2 drive pulley | 20 teeth, 2mm pitch, 6mm belt, 5mm motor bore | Salvaged printer pulley | required
mechanical | up to 8 | GT2 idler pulley | For 6mm belt and M5 axle; smooth or toothed to match contacted belt face | Salvaged printer idler | required by routing
mechanical | about 4m | GT2 timing belt | 2mm pitch, 6mm wide, reinforced | Salvaged printer belt if undamaged | required
mechanical | 8-10 | 90-degree frame bracket | Compatible with 20x20 extrusion | Salvaged aluminium or attributed printable bracket | required by layout
mechanical | about 30 | M5 T-nut | Matches extrusion slot | Salvaged printer T-nut | required by layout
mechanical | assorted | M5 screw assortment | M5x8/10/12 for brackets and M5x20/25/30/35 for axle stacks | Salvaged printer screws | verify each stack
mechanical | 8 | M3 motor screw | M3x8-10 or verified non-bottoming length | Salvaged printer screws | required
mechanical | as needed | M2/M3 printed-part hardware | Matches switch and printed support holes | Assorted donor hardware | required by layout
mechanical | 1 set | Belt anchors and tensioners | Retains belt without tooth damage and permits adjustment | Printed and donor parts | required
board | 64 | Printed board tile | 37.5mm pitch and protected reed pocket | Project-authored common tile | required
board | 1 | Enclosure and board support | Flat 300x300mm playing field with service access | Project-authored enclosure | required
board | 4 | TPU frame spacer | Matches built case and frame | Project-authored front/back left/right spacers | optional by enclosure
pieces | 1 set | Chess pieces | Magnet-ready bases and low-friction movement | Prototype chess set | required
pieces | 32 | Piece magnet | 5x2mm neodymium starting option, consistent pole orientation | Magnet option used by project catalog | required
pieces | as needed | Low-friction base material | Thin enough to preserve reed activation | Felt or equivalent | optional

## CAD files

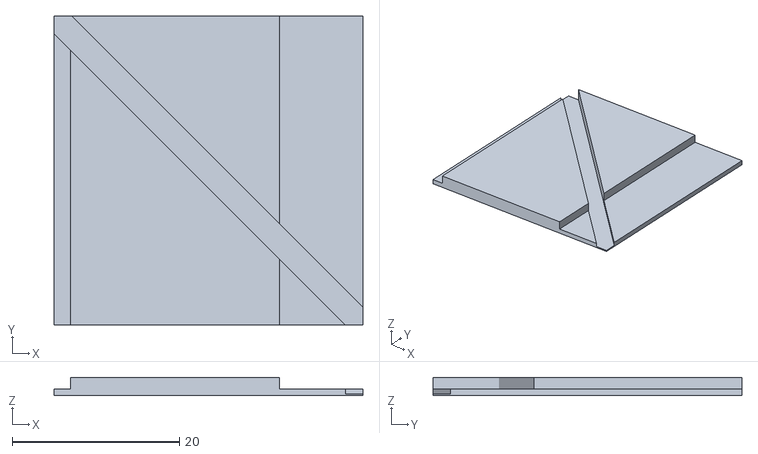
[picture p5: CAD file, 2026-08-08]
hardware/printFiles/project_authored/board_tiles/chessboard_tile_with_sensor_cutout.stl
37.0 x 37.0 x 2.20

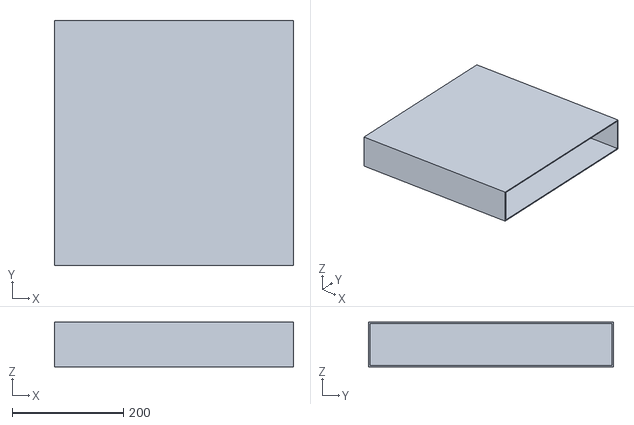
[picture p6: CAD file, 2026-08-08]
hardware/printFiles/project_authored/enclosure/case.stl
430.0 x 440.0 x 80.4

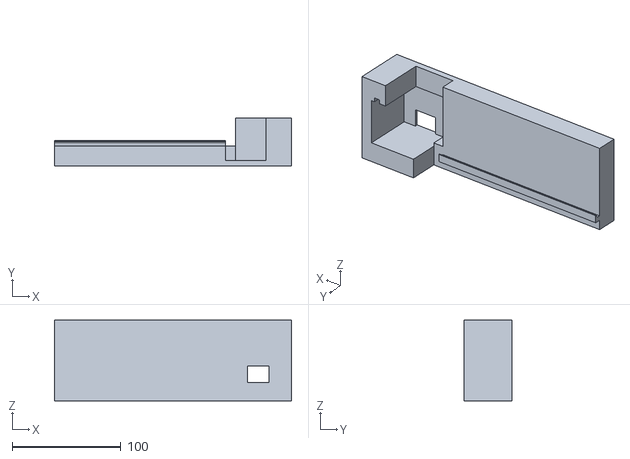
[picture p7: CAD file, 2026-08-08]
hardware/printFiles/project_authored/frame_spacers/front_case_spacer_left_tpu.stl
217.5 x 44.5 x 74.0

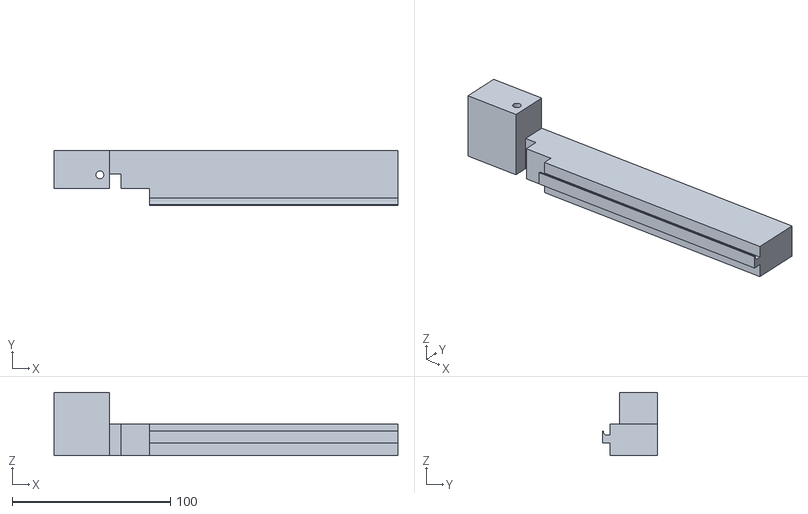
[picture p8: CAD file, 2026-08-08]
hardware/printFiles/project_authored/frame_spacers/back_case_spacer_left_tpu.stl
217.5 x 35.0 x 40.0

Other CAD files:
hardware/printFiles/project_authored/frame_spacers/front_case_spacer_right_tpu.stl
hardware/printFiles/project_authored/frame_spacers/back_case_spacer_right_tpu.stl

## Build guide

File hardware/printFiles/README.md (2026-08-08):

# 3D-print files

This directory separates models created for this project from third-party
models that have their own authors and license terms.

## Project-authored models

The files in [`project_authored`](project_authored/) were designed for this
Automatic Chessboard project:

- `enclosure/` contains the tested outer case; the complete mechanism slides
  into it from the front.
- `board_tiles/` contains the common chessboard tile with a sensor cutout.
- `frame_spacers/` contains the four TPU parts attached at the front and rear
  of the internal body. They center and support it inside the case while
  reducing vibration and rattling.

The photographed construction, tested enclosure settings, glass-board recess,
and direct-to-case tile alternative are documented in
[`PROTOTYPE.md`](../PROTOTYPE.md).

These project-authored models are covered by the repository's
[CC BY-NC-SA 4.0 license](../../LICENSE.md). They are part of a modified build
derived from the Greg06 Automated Chessboard project; see
[`ATTRIBUTION.md`](../../ATTRIBUTION.md).

## Third-party models

Third-party models are stored under [`third_party`](third_party/) with their
source information, attribution, original documentation, and license files.
Do not assume that one third-party model's license applies to another model or
to the project-authored files.

| Model | Creator | Source | License |
| --- | --- | --- | --- |
| Automatic Chessboard | Passe06 | [Thingiverse 5191069](https://www.thingiverse.com/thing:5191069) | [CC BY 4.0](https://creativecommons.org/licenses/by/4.0/) |
| 2020 V-Slot Aluminium Profile | icimdengelen | [Thingiverse 4859905](https://www.thingiverse.com/thing:4859905) | [CC BY 4.0](https://creativecommons.org/licenses/by/4.0/) |
| Corner Bracket (20x20x20mm) | Michaelo | [Thingiverse 2504141](https://www.thingiverse.com/thing:2504141) | [CC BY 4.0](https://creativecommons.org/licenses/by/4.0/) |

## Optional printed V-slot components

The third-party [`2020 V-Slot Aluminium Profile`](third_party/icimdengelen_2020_vslot_aluminium_profile_4859905/)
model is included for builders who want to investigate printing a 20 x 20 mm
V-slot profile instead of using an aluminium extrusion. The third-party
[`Corner Bracket (20x20x20mm)`](third_party/michaelo_corner_bracket_20x20x20mm_2504141/)
package provides M3- and M5-nut bracket variants for joining compatible
20 x 20 mm extrusions.

For this chessboard, a complete rail replacement set must finish at these
longitudinal lengths while retaining the 20 x 20 mm cross-section:

| Qty | Length | Intended role |
| ---: | ---: | --- |
| 2 | 345 mm | Side frame rails |
| 1 | 350 mm | Long frame cross rail |
| 1 | 315 mm | Short frame cross rail |
| 1 | 395 mm | Moving gantry rail |

Change or segment only the model's longitudinal axis; uniformly scaling the
STL would make its V-slot cross-section incompatible with the wheels and
brackets. See [`MECHANICAL.md`](../MECHANICAL.md) for structural and acceptance
requirements.

Printed plastic parts should not be assumed to match the stiffness, strength,
wear resistance, or dimensional accuracy of aluminium components; validate the
material, print settings, dimensions, fastener fit, and loaded behavior before
relying on them in the machine.

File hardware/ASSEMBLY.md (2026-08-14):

# Staged assembly

Build and test one subsystem at a time. Do not populate everything and apply
24 V for the first test.

## 1. Label and inspect

1. Print `connections.csv` and `sensor-map.csv`, or keep them open beside the
   work area.
2. Label both ends of every motor, switch, magnet, and sensor cable.
3. Photograph every carrier's pin labels and sense-resistor markings before
   mounting a heatsink.
4. Inspect the Nano and module undersides for solder bridges.
5. Verify all polarized parts: supply connector, buck, both 100 uF capacitors,
   flyback diode, and reverse-polarity stage.

## 2. Build the protected 24 V input

With no electronics connected, wire the inlet, 3 A time-delay fuse, latching cutoff,
reverse-polarity protection, and covered distribution block. Use red for
protected +24 V and black for common GND where practical.

Power this stage alone. Verify 23-25 V at the distribution block and verify the
cutoff removes it. Disconnect power.

## 3. Configure the buck alone

Connect only the buck input through its logic fuse. Leave its output floating.
Power on, set the output to 5.00 V, switch off, wait for discharge, and mark the
adjuster so accidental movement is visible.

## 4. Build and test the 5 V logic rail

Connect the buck output to a 5 V distribution point. Connect the Nano `5V`
pin, all four multiplexer `VCC` pins, both driver `VDD` pins, the LCD, and the
HC-08 carrier. Connect every logic ground to the common GND point.

Do not connect `VMOT`, motors, or the magnet yet. Power the logic rail and
complete the logic-only commissioning stage.

## 5. Wire the reed system

Share `S0-S3` and `SIG` exactly as shown in `WIRING.md`. Give each multiplexer
its own enable wire. Connect and validate one multiplexer (16 squares) at a
time before adding the next. This makes a reversed ribbon cable or off-by-one
channel visible immediately.

## 6. Wire switches, LCD, and Bluetooth

Add the two normally-open switch circuits, including the external 10 kohm A6
pull-up. Add the LCD and confirm that the `hd44780_I2Cexp` diagnostic detects
its backpack; the firmware does not require one fixed PCF8574 address. Add the
HC-08 resistors and cover each resistor lead and solder joint with heat-shrink.

If reusing the fabricated long PCB, do not use its legacy D10 switch connector.
Wire HC-08 `TXD` through 1 kohm to D10, move the second switch to A6 with its
10 kohm pull-up to 5 V, and add the D1-to-HC-08 divider exactly as shown in
`WIRING.md`. Complete every missing PCB net with secured external wiring and
continuity-test it against `connections.csv`. The board is proven functional
with this rework; the archived layout is not correct without it.

## 7. Build the magnet switch

Wire the TIP120, 1 kohm base resistor, 10 kohm base pull-down, magnet, and
flyback diode. Confirm the diode stripe is on the +24 V side. Keep the magnet's
24 V branch disconnected until the service-output test.

## 8. Prepare the two motor drivers

1. Identify every carrier pin from its silkscreen.
2. Tie `RESET` to `SLEEP` and then to 5 V.
3. Tie `MS1`, `MS2`, `MS3`, and `ENABLE` to GND for the documented full-step
   mode.
4. Add one independent 10 kohm resistor from each `STEP` and `DIR` input to
   logic GND: four pull-downs total. Place them near the carrier inputs; do not
   put them in series or share one resistor between two signals.
5. Add a 100 uF/50 V capacitor directly across each `VMOT`/GND pair.
6. Identify each motor's two coil pairs with a meter.
7. Twist the two conductors of coil A together and twist the two conductors of
   coil B together. With power removed, connect both coils.
8. Route each `STEP` signal with a logic-GND return and each `DIR` signal with
   a logic-GND return. Keep these logic routes short and separate from motor,
   fan, electromagnet, and 24 V wiring as specified in `WIRING.md`.
9. Set a conservative VREF, then follow the current-limit procedure in
   `WIRING.md`. The prototype's final value is 0.720 V only for its R100 boards
   and donor motors.

## 9. Bench harness inspection

- Tug-test every crimp and terminal.
- Cover all exposed power terminals.
- Ensure no belt can touch a cable.
- Ensure the cutoff remains accessible with the board closed.
- Check continuity from every module ground to the GND bus.
- Check that +24 V is not continuous to 5 V, Nano pins, or the frame.
- Confirm motor, fan, magnet, and 24 V bundles do not run parallel against
  `STEP`, `DIR`, switch, Bluetooth, or sensor wiring. Cross unlike bundles at
  approximately 90 degrees where separation is impossible.
- Confirm cable clips and strain relief do not put tension on driver headers,
  crimps, solder joints, or the VREF adjusters.

Do not install the harness into the moving frame until these checks pass.

## 10. Dry-assemble the donor-printer frame

1. Inventory the V-slot rails, V-wheels, eccentric and fixed spacers, shims,
   brackets, T-nuts, screws, pulleys, idlers, belts, and both motors against
   `BOM.md`.
2. Identify and label the five 20 x 20 mm rails before adding brackets:
   two `345 mm` side rails, one `350 mm` cross rail, one `315 mm` cross rail,
   and the `395 mm` moving-gantry rail.
3. Reject bent rails, cracked wheels, rough bearings, damaged belt teeth,
   rounded set screws, and connectors with heat damage.
4. Assemble the outer rails loosely on a flat surface. Measure both diagonals
   and adjust until they match before tightening the corner brackets.
5. Install the 395 mm moving gantry and trolley. Turn eccentric spacers only far
   enough to remove play; every carriage must still roll freely by hand.
6. Confirm the carriage can reach all 64 square centers and both switch
   actuators without a belt installed.

The lengths in `BOM.md` are the confirmed finished lengths for this build. A
different bracket, wheel plate, or endstop design can change the required
geometry, so complete the reach and collision checks before treating them as a
drop-in cut list for a modified frame.

## 11. Install pulleys and CoreXY belts

1. Seat each 20-tooth drive pulley on the motor shaft with one set screw on the
   shaft flat where available. Tighten the second set screw after alignment.
2. Use smooth idlers where the belt back contacts the pulley and toothed idlers
   where the tooth side must bend. Fit washers or shims so belt flanges do not
   rub the bracket.
3. Route the two belt paths symmetrically. They must remain in their own planes
   and must not cross by touching or rubbing.
4. Anchor and tension each path independently. Remove slack without bowing the
   gantry or making the carriages hard to move.
5. Move the trolley through the full envelope by hand. The belt must stay
   centered and the gantry must remain square.

Do not assume a salvaged belt is serviceable merely because it is unbroken.
Replace it if teeth are polished, cracked, stretched, or separating from the
reinforcement.

## 12. Fit the board tiles and sensor harnesses

1. Dry-fit all 64 tiles on a 37.5 mm pitch and check the 300 x 300 mm playing
   field for flatness before adding sensors or adhesive.
2. Build eight labelled sensor banks. Each bank needs eight square signals and
   a common ground return to its assigned multiplexer channels.
3. Support each reed-switch lead before bending it. Fit the switch into its
   pocket without twisting or loading the glass capsule.
4. Validate each bank electrically before gluing it into the board.
5. Route and retain the harnesses outside the carriage and belt envelope, then
   repeat the complete 64-square sensor test.

## 13. Prepare the chess pieces

1. Use one magnet size and grade for the full set; 5 x 2 mm neodymium discs are
   the documented starting option, not a guarantee for every tile and piece.
2. Mark one pole of every magnet before installation and keep the same pole
   facing the board in all 32 pieces.
3. Retain each magnet mechanically where practical and use an adhesive suitable
   for both the magnet coating and piece material.
4. Add felt or another low-friction base only after confirming that the added
   gap does not prevent reed activation or reliable pickup.
5. Test every finished piece on every square before closing the enclosure.

## 14. Fit the sliding chassis and playing surface

1. Attach the two front and two rear TPU spacers to the completed internal
   body. Confirm they cannot move into a belt, wheel, or pulley path.
2. With power removed and service cables disconnected or safely supported,
   slide the body into the outer case from the front. The spacers should center
   and steady it without requiring enough force to distort the V-slot frame.
3. Choose one playing-surface construction:
   - support the glass-backed tile board in a case-top opening, as on the
     prototype; or
   - attach the tiles and supported sensors directly to the intact case top.
4. For a recessed glass board, support the plate on a level distributed ledge,
   protect its edges, and retain it against lift and horizontal movement. Cut
   only the printed case, not glass with unknown tempering.
5. Reconnect the eight sensor banks with strain relief and enough service loop
   to remove the body again. Keep every ribbon outside the carriage envelope.
6. Check board flatness, carriage clearance, sensor operation, and pickup on
   all 64 squares before fitting cosmetic covers.

The prototype case used a 0.8 mm nozzle, three perimeters, and approximately
2.4 mm walls/top/floor. Other print settings are valid if they meet the same
support, clearance, vibration, and serviceability requirements. See
`PROTOTYPE.md` for photographs and the reason for the recessed glass option.

## 15. Final mechanical and electrical integration

Mount the electromagnet with mechanical retention, add flexible strain relief,
and verify a uniform under-board gap through the full travel. Install the
controller so driver potentiometers, fuses, terminals, and the USB connector
remain serviceable. Keep the latching cutoff reachable with the board closed.

Additional covers may hide the controller and wiring, but they must remain
removable and must not obstruct cooling, fuse replacement, connector access,
the cutoff, or the body's front slide-out path.

Repeat the bench continuity tests after installation. Then sign and date the
commissioning checklist and follow `COMMISSIONING.md` from the logic-only stage;
do not skip directly to calibration or piece-carrying tests.

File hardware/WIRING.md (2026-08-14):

# Wiring and firmware pin contract

This page is the human-readable source of truth. The same point-to-point data
is in `connections.csv` and `sensor-map.csv`.

## Nano pins

| Nano pin | Function | Connect to | Electrical behavior |
| --- | --- | --- | --- |
| D0/RX | USB serial receive | Onboard USB bridge only | Do not connect HC-08 TX here |
| D1/TX | Shared reply transmit | 1 kohm then HC-08 RXD node; 2 kohm from node to GND | Divider produces about 3.3 V |
| D2 | Motor 1 direction | Driver 1 `DIR`; separate 10 kohm from `DIR` to logic GND | Firmware name `MOTOR_WHITE_DIR`; defaults LOW during reset |
| D3 | Motor 1 step | Driver 1 `STEP`; separate 10 kohm from `STEP` to logic GND | Firmware name `MOTOR_WHITE_STEP`; defaults LOW during reset |
| D4 | Motor 2 direction | Driver 2 `DIR`; separate 10 kohm from `DIR` to logic GND | Firmware name `MOTOR_BLACK_DIR`; defaults LOW during reset |
| D5 | Motor 2 step | Driver 2 `STEP`; separate 10 kohm from `STEP` to logic GND | Firmware name `MOTOR_BLACK_STEP`; defaults LOW during reset |
| D6 | Electromagnet control | 1 kohm to TIP120 base | HIGH energizes magnet |
| D7 | MUX 3 enable | MUX 3 `EN` | Active LOW |
| D8 | MUX 2 enable | MUX 2 `EN` | Active LOW |
| D9 | MUX 1 enable | MUX 1 `EN` | Active LOW |
| D10 | Bluetooth receive | HC-08 TXD through 1 kohm | Receive-only software UART |
| D11 | Button/limit A | Normally-open switch to GND | Internal pull-up; pressed is LOW |
| D12 | Shared sensor input | All four MUX `SIG` pins | Internal pull-up; occupied is LOW |
| D13 | MUX 0 enable | MUX 0 `EN` | Active LOW; onboard LED may blink during scans |
| A0 | MUX address bit 3 | All MUX `S3` pins | Shared address bus |
| A1 | MUX address bit 2 | All MUX `S2` pins | Shared address bus |
| A2 | MUX address bit 1 | All MUX `S1` pins | Shared address bus |
| A3 | MUX address bit 0 | All MUX `S0` pins | Shared address bus |
| A4 | I2C data | LCD `SDA` | 5 V I2C bus |
| A5 | I2C clock | LCD `SCL` | 5 V I2C bus |
| A6 | Button/limit B | Normally-open switch to GND, plus 10 kohm to 5 V | Analog-only input; pressed is LOW |
| 5V | Logic rail | Buck 5.0 V, drivers `VDD`, MUX `VCC`, LCD VCC, HC-08 carrier VCC | Do not use VIN for a 5 V buck |
| GND | Common reference | Every 5 V and 24 V subsystem ground | Use a low-resistance distribution point |
| VIN | Unused | Nothing in this design | Classic Nano VIN expects 7-12 V |

The motor names `WHITE` and `BLACK` are inherited firmware identifiers. They
do not define motor wire colors or a universal left/right mounting position.
Verify each axis in the guarded service test before calibration.

## Power tree

Wire the positive path in this order:

```text
24 V supply + -> F1 3 A time-delay -> latching cutoff -> reverse-polarity stage -> +24V_BUS
24 V supply - ---------------------------------------------------------------> GND_BUS

+24V_BUS -> driver 1 VMOT
+24V_BUS -> driver 2 VMOT
+24V_BUS -> electromagnet positive
+24V_BUS -> logic-fused buck IN+
GND_BUS  -> both driver motor GND pins, TIP120 emitter, buck IN-, and all logic GND

buck OUT+ (adjusted to 5.00 V) -> Nano 5V and 5V logic rail
buck OUT- ---------------------> GND_BUS
```

Mount a 100 uF/50 V capacitor directly at each driver: capacitor `+` to
`VMOT`, striped `-` lead to the adjacent motor `GND`. Long wires before the
capacitor do not replace local decoupling.

## Stepper drivers

For each StepStick-compatible carrier:

| Driver pin | Connection |
| --- | --- |
| `VMOT` | Protected +24 V bus |
| Motor `GND` beside VMOT | Common GND and capacitor negative |
| `VDD` | Regulated 5 V |
| Logic `GND` beside VDD | Common GND |
| `RESET` and `SLEEP` | Tie together, then connect to 5 V |
| `MS1`, `MS2`, `MS3` | GND for explicit full-step operation |
| `ENABLE` | GND for explicit enabled operation |
| `STEP`, `DIR` | Nano pins listed above; each input also has its own 10 kohm pull-down to logic GND |
| `1A`, `1B` | The two wires of motor coil A |
| `2A`, `2B` | The two wires of motor coil B |

Carrier labels, not board color or component-side orientation, are
authoritative. With all power removed and the motor disconnected, use a meter
to find the two low-resistance wire pairs. One pair goes to `1A/1B`; the other
goes to `2A/2B`. Swapping both wires of one coil reverses that motor. Never mix
one wire from each coil into a pair.

An early prototype left `MS1-3` and `ENABLE` open and could appear to work
because its carriers provided low defaults. Do not copy that wiring. Connect
these pins explicitly as shown above so correct operation does not depend on
weak internal bias resistors or an undocumented clone-board implementation.

Install four independent 10 kohm pull-downs: one from each driver's `STEP` and
`DIR` input to that carrier's logic GND. Place them near the carrier inputs;
they are shunt resistors, not series resistors, and `STEP` and `DIR` must not
share one resistor. A driven 5 V HIGH sources only 0.5 mA through each
pull-down. The working prototype uses all four resistors, which keep the
otherwise floating A4988-compatible inputs LOW while the Nano starts or resets.

### Motor wiring layout and interference control

Stepper outputs switch substantial current at high frequency. A driver can be
electrically correct on the bench yet lose holding torque or stop after it is
installed beside long, parallel power and signal wiring. Treat physical cable
routing as part of the circuit:

- Twist `1A` with `1B` as one motor-coil pair and twist `2A` with `2B` as a
  second pair. Do not twist one conductor from each coil together.
- Run `STEP` beside a logic-GND return and `DIR` beside a logic-GND return.
  Keep both routes short and keep their pull-down resistors at the carrier.
- Twist each fan's positive and negative supply wires together. Route fan,
  motor, electromagnet, and 24 V wiring separately from Nano, Bluetooth,
  switch, reed-sensor, `STEP`, and `DIR` wiring.
- Maximize separation between switched-power and logic bundles. There is no
  universal minimum distance; validate the final enclosure layout. If bundles
  must cross, cross once at approximately 90 degrees rather than running them
  parallel.
- Give each driver a short, low-resistance ground path to the common
  distribution point. Do not make logic current return through a long motor or
  fan ground wire. Keep the local `VMOT` capacitor at the carrier.
- Add strain relief so installing a cover or moving a harness cannot bend a
  connector, pull a crimp, or change a solder joint.

Never add pull-down resistors to `1A`, `1B`, `2A`, or `2B`. They are driven
H-bridge outputs, not floating logic inputs. Never connect a motor-output wire
to logic GND, chassis, or cable shield. If shielded signal cable is required
after routing has been corrected, terminate its shield at the controller end
only and keep the shield isolated from every signal and motor conductor.

Human proximity changing motor behavior is not normal. First verify the local
`STEP`/`DIR` pull-downs and explicit control-pin levels, then separate cable
groups. If repositioning a whole group fixes the fault, repeat the test with
one group at a time. A failure that follows distance from another bundle points
to coupled interference; a failure that follows bending or tension points to
an open conductor, connector, solder joint, or PCB trace. Use a nonconductive
temporary fixture for diagnosis, then replace it with secured plastic
standoffs, clips, or a printed bracket. Paper or cardboard is not a permanent
electronics mount.

### Current limit

The photographed HR4988SQ boards contain two `R100` resistors, so:

```text
I_limit = VREF / (8 x 0.10 ohm)
VREF = 0.8 x desired current in amperes
```

| VREF | Approximate limit on this R100 carrier |
| ---: | ---: |
| 0.40 V | 0.50 A |
| 0.48 V | 0.60 A |
| 0.56 V | 0.70 A |
| 0.64 V | 0.80 A |
| 0.72 V | 0.90 A (tested prototype setting) |

Use the motor's rated phase current when known. If it is unknown, start lower,
test unloaded motion, and increase only enough to avoid missed steps while
watching temperature. Recalculate the table if the sense resistors are not
`R100` or the carrier documentation specifies a different relationship.

## Electromagnet driver

TIP120 magnet circuit

- H2520 positive -> protected +24 V.
- H2520 negative -> TIP120 collector (middle lead on the documented TO-220
  part when viewed from the marked front).
- TIP120 emitter -> GND.
- Nano D6 -> 1 kohm -> TIP120 base.
- 10 kohm from TIP120 base to GND keeps the magnet off during reset.
- Flyback diode directly across the magnet: **stripe/cathode to +24 V**,
  unstriped/anode to the collector/magnet-negative node.

The 24 V / 2.8 W magnet draws about 117 mA nominal. The diode is mandatory even
at this modest current because the coil produces a voltage spike when switched
off.

## LCD, buttons, and Bluetooth

```text
LCD:   GND -> GND, VCC -> 5V, SDA -> A4, SCL -> A5

SW A:  D11 ---- normally-open switch ---- GND
SW B:  A6  ---- normally-open switch ---- GND
       A6  ---- 10 kohm ----------------- 5V

HC-08 TXD ---- 1 kohm ---- D10

Nano D1/TX --- 1 kohm ---+--- HC-08 RXD
                          +--- 2 kohm --- GND

HC-08 carrier VCC -> 5V
HC-08 GND         -> GND
```

The 5 V connection is for an HC-08 **carrier with an onboard regulator**, as
used in the prototype. A bare 3.3 V module must not be powered from 5 V. Keep
the D1 divider even when the carrier accepts a 5 V supply; supply tolerance
does not prove that its RX logic input is 5 V tolerant.

## Reed sensors and multiplexers

All four modules share `S0-S3`, `SIG`, 5 V, and GND. Each module has its own
active-low `EN` pin. Each normally-open reed switch connects between one `C0`
through `C15` channel and GND. A nearby piece magnet closes the switch and the
firmware reads LOW.

The exact 64-square channel assignment is in `sensor-map.csv` and shown in the
sensor diagram. Viewed by logical chess coordinates:

| MUX | EN pin | C0-C7 | C8-C15 |
| ---: | --- | --- | --- |
| 0 | D13 | a2-h2 | a1-h1 |
| 1 | D9 | a8-h8 | a7-h7 |
| 2 | D8 | a6-h6 | a5-h5 |
| 3 | D7 | a4-h4 | a3-h3 |

This unusual rank order is deliberate and matches the glued-tile prototype
and firmware `SENSOR_ROW_MAP`. Do not silently rearrange it into numerical
rank order.

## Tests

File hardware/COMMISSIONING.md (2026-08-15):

# First-power commissioning

Use a multimeter for every voltage step. Do not skip ahead after a failed
measurement.

## Record sheet

| Measurement | Acceptable | Actual |
| --- | --- | --- |
| Protected 24 V bus | 23.0-25.0 V | |
| Buck output before logic connection | 4.90-5.10 V | |
| Nano 5V to GND | 4.80-5.15 V | |
| Driver 1 VDD | 4.80-5.15 V | |
| Driver 2 VDD | 4.80-5.15 V | |
| Driver 1 VMOT | 23.0-25.0 V | |
| Driver 2 VMOT | 23.0-25.0 V | |
| Driver 1 VREF and sense marking | Record; 0.720 V / R100 is prototype value | |
| Driver 2 VREF and sense marking | Record; 0.720 V / R100 is prototype value | |
| A6 released / pressed raw ADC | Above 512 / below 512 | |

## Stage A: power-off checks

1. Disconnect USB and 24 V.
2. Confirm both electrolytic capacitor stripes go to GND.
3. Confirm each flyback diode stripe goes to +24 V.
4. Confirm both drivers face the correct direction by reading pin labels.
5. Confirm four separate 10 kohm resistors connect driver 1 and driver 2
   `STEP` and `DIR` individually to their logic GND pins. Confirm the signal
   inputs are not connected to each other.
6. Confirm each driver's `MS1`, `MS2`, `MS3`, and `ENABLE` pins connect
   directly to logic GND, and its tied `RESET`/`SLEEP` pins connect to 5 V.
7. Confirm no motor-output conductor (`1A`, `1B`, `2A`, or `2B`) connects to
   logic GND, chassis, or a cable shield.
8. Confirm no short between protected +24 V and GND. A capacitor-charging
   reading that rises is normal; a steady near-zero resistance is not.
9. Confirm no short between 5 V and GND.
10. Confirm every motor has two isolated coil pairs and no motor wire is shorted
   to the frame.
11. Confirm the two conductors of each motor coil are twisted as a pair and
    switched-power bundles are separated from logic and sensor wiring.
12. Press each limit switch and verify it closes to GND.

## Stage B: protected input and 5 V logic only

Leave driver `VMOT`, motors, and magnet 24 V disconnected.

1. Apply 24 V and record the protected bus and buck output.
2. Test the latching cutoff three times. The 24 V and 5 V rails must both fall.
3. Boot the Nano and LCD.
4. Connect the Windows app by BLE or, with external power removed, by USB.
5. Run **Diagnostics -> Run safe diagnostics**. Connecting and diagnostics must
   cause no motor or magnet activity.
6. Verify the monitor reports firmware 4.6.0 and fresh telemetry.

For a differently sized or positioned playing field, finish normal switch and
motion commissioning first, then use **Board alignment** on Windows or **Move >
Align board** on Android as documented in `firmware/README.md`. Head-only visual
alignment is the default; a visible magnetic marker is optional. Reed sensors,
a calibration sheet, and a camera are not required. Rebuild and upload the
reported constants, calibrate, then verify separated squares. Terminal-only
builders can use the documented `GEOMETRY`, `ALIGN`, and `NUDGE` commands.

## Stage C: switches and 64 sensors

1. Observe both switch states released.
2. Run the firmware's guided `SWTEST` from the app developer console or a
   serial terminal.
3. Follow its prompts to press/release switch A/D11 and then switch B/A6. It
   must report `SWTEST PASS`; record the pressed A6 raw value.
4. Place one magnet-equipped piece on each square, one at a time.
5. Confirm exactly the matching square changes in the visual board.
6. Remove the piece and confirm the square clears.

Do not continue until all 64 squares pass. If a whole rank is wrong, check the
multiplexer/channel table; do not compensate by relabelling the UI.

## Stage D: magnet branch

Keep motor VMOT disconnected and secure the carriage away from steel objects.

1. Connect the magnet's protected 24 V branch.
2. Use the guarded service magnet control for a one-second pulse.
3. Verify the magnet energizes only when commanded and releases afterward.
4. Trigger the physical cutoff while energized; it must release immediately.
5. If the Nano resets or the LCD corrupts, stop and inspect common-ground
   routing, the flyback diode, and supply decoupling.

## Stage E: one motor at a time

1. Remove all pieces and expose the mechanism.
2. Connect driver 1 VMOT and its motor with power off.
3. Keep the untested driver's VMOT and the protected magnet 24 V branch
   physically disconnected before and throughout the JOG test.
4. Apply power and run `JOG W+` then `JOG W-` for the white driver, or
   `JOG B+` then `JOG B-` for the black driver, from a guarded developer
   console. Each command moves only 20 full steps.
5. Verify smooth motion. Grinding or vibration usually indicates mixed coil
   pairs; stop power before changing wires.
6. Verify direction against the expected switch. Reverse one complete coil
   pair only if necessary.
7. Stop issuing steps and verify the motor retains steady holding torque in
   full-step mode. Weak torque at particular positions or complete loss of
   holding torque is a stop condition, not an acceptable resonance effect.
8. Repeat for driver 2.
9. Record both VREF values and temperatures after 15 minutes of unloaded test.
10. With power removed before every routing change, test the intended final
    cable layout and then rerun both motors. If behavior changes with cable
    position, isolate one motor, fan, magnet/power, or logic bundle at a time as
    described in `WIRING.md`; do not proceed until the final secured layout is
    repeatable.

## Stage F: calibration and endurance

1. Restore both drivers and keep the surface open.
2. Actuate both limit switches by hand while watching the visual state.
3. Start calibration with one hand beside the physical cutoff.
4. Confirm the first approach moves toward the D11/white switch and stops on
   it, then the second approach finds the A6/black switch.
5. Confirm the carriage parks at e6 without striking an end stop.
6. Close the surface and test empty-board sensor stability.
7. Test one piece on direct horizontal, vertical, and diagonal moves. Test a
   knight through connected Play and verify it becomes separate straight
   square-centre drags; no continuous knight or S-shaped carry is permitted.
   Place a stationary piece on either shared corner of a diagonal and verify
   standalone play requests a manual move without energizing the magnet.
8. Test an automatic capture first with its direct lower-left boundary lane
   empty, then with that lane blocked but a vertically reachable lane clear.
   Verify a fully blocked exit requests the displayed move manually and causes
   no capture motion.
9. Optionally run the connected magnet-free endurance test documented in
   `../firmware/README.md`, with an empty board and someone beside the cutoff.

## Stop conditions

Cut physical power immediately for uncontrolled motion, smoke, odor, a hot or
swelling capacitor, a slipping belt that can tangle wiring, repeated Nano
resets, lost motor holding torque, a magnet that remains energized, or a limit
switch that does not stop homing. Diagnose with 24 V removed.

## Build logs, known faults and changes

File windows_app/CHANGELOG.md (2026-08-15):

# Changelog

## Unreleased

- Added standalone turning-piece routing in firmware 5.0.1. A Micro-Max knight,
  or any AI piece whose direct line is blocked, now follows a shortest empty
  orthogonal square-centre route. Manual placement remains the fallback only
  when no such route connects the source and destination.
- After a user-confirmed manual capture removal, standalone play now reruns the
  same route search and moves the AI piece automatically whenever reachable.
- Released the coordinated 5.0 protocol: exact `HELLO 5.0.0` gating, fixed
  current feature contract, and no `PLAY`, `PING`, `STATUS`, or old-firmware
  fallback paths. Apps and Nano must be updated together.
- Added full-board standalone capture routing. The Nano now finds a shortest
  empty orthogonal path to any `a1`-`a8` bin exit and requests manual completion
  only when no exit is reachable.
- Added capture routing through arbitrary empty square-centre paths to any
  `a1`-`a8` bin exit,
  so reachable detours beat moving an unrelated piece. The Nano tracks every
  verified capture drag.
- Added firmware-4.7 deferred capture removal. The route search can now park
  blockers before `REMOVE`, prove the capture frame, complete the main move,
  and restore every temporary piece in one transaction.
- Added firmware-4.6 app-controlled play for absent or unreliable reed switches.
  Human and Stockfish moves share the collision-safe route planner, and every
  completed move requires whole-board visual confirmation before play continues.
- Added an interactive Play board, explicit sensor/app authority selection,
  virtual-board simulator coverage, and stop-on-mismatch/disconnect recovery.
- Added a recoverable firmware-4.5 board-alignment workflow with user-selected
  squares, one-step X/Y controls, optional magnetic-marker mode, reconnect
  recovery, two-point geometry calculation, and copyable `global.h` values.
- Corrected displayed and simulated telemetry-state numbers to the firmware's
  stable 0-20 state contract.
- Aligned direct manual movement and the simulator with firmware 4.4's
  file/rank/diagonal-only carry contract. Turning moves remain available through
  the collision-safe square-centre route planner.

## 1.2.0

- Added host-side labeled rearrangement planning for collision-safe automatic
  moves on firmware 4.3.
- Added bounded blocker evacuation/restoration, main-piece staging, and recursive
  clearing for trapped blockers.
- Added transactional `PLAN` / straight `DRAG` / `COMMIT` execution with fresh
  64-square proofs after every physical action.
- Added capture, en passant, promotion, and standard-castling route adaptation;
  Chess960 is rejected explicitly until its physical rook mapping is supported.
- Added immutable worker-thread planning, stale-generation rejection, separate
  control/motion timeouts, and conservative uncertain-state recovery.
- Made route cost account for every real pickup created when a turning path is
  split into straight firmware runs.
- Added planner, protocol, simulator, and chess-adapter regression coverage.
- Added an exhaustive motionless Nano transaction model, read-only serial probe,
  and one-command firmware/Windows/Android validation workflow for contributors
  without functional motion or reed hardware.
- Aligned both app simulators with firmware 4.3 homing, remote-state, promotion,
  and four-coordinate `DONE` behavior.
- Added routing architecture and safety documentation plus a versioned release
  ZIP produced by the build script.
- Retained `PLAY` compatibility for firmware 4.0 and earlier.

## 1.1.0

- Added guarded in-app calibration, head-only moves, and click-source/click-target
  piece moves with fresh telemetry and sensor verification.
- Added firmware capabilities for manual movement and complete 64-square frames.
- Added stronger connection loss, stale-state, and command-risk handling.

## 1.0.0

- Added visual logical/physical board comparison and carriage overlay.
- Added ACB2 firmware identity and live telemetry.
- Added mechanism, limit input, magnet, memory, uptime, and stale-state displays.
- Added resilient BLE/USB reconnect and bounded safe polling.
- Added best-effort emergency halt checked inside Nano motion loops.
- Added guided non-motion diagnostics and privacy-sanitized support bundles.
- Added optional USB/RTSP/HTTP camera view with explicit snapshots only.
- Added simulator mode and command-risk gating for contributors.
- Added public documentation, tests, Windows build script, issue template, and CI.
- Added fixed reed-sensor rank normalization for the published glued-tile wiring.
- Serialized every read-only request path so setup, diagnostics, developer reads,
  and background monitoring cannot overlap on a slow BLE link.
- Added atomic settings saves, bounded session-log retention, and board-aware BLE
  discovery ranking.
- Required fresh PONG, INFO, TELEM, and BOARD evidence from the current
  diagnostic batch so timed-out requests cannot pass using cached data.

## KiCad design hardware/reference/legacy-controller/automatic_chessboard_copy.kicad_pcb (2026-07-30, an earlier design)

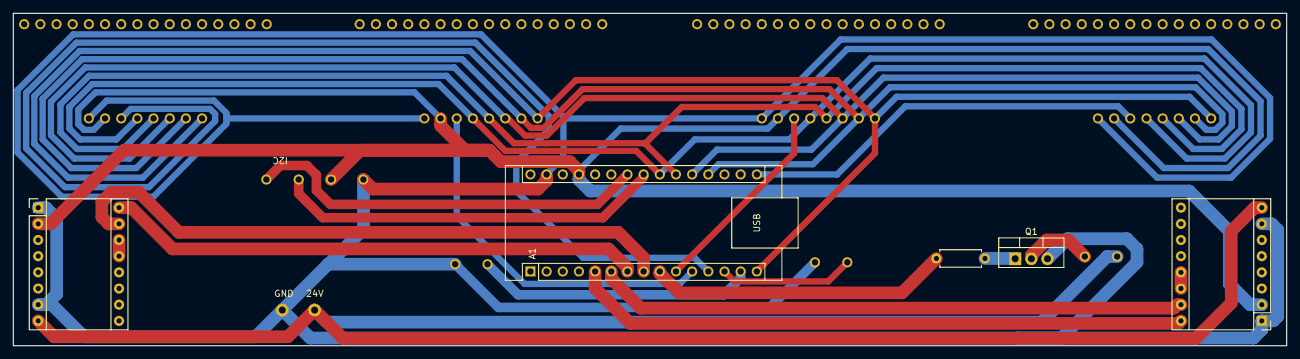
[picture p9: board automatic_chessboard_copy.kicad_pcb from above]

Board: 2 copper layers, 200.0 x 52.2 mm, 14 parts (0 on the bottom side), 25 nets.

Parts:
A1: Arduino Nano; Arduino_Nano
A2, A3: A4988; Pololu_Breakout-16_15.2x20.3mm
I2C: i2c display
L1: L; electromagnet_pins
Q1: TIP120; TO-220-3_Vertical
R1: 1k; R_Axial_DIN0207_L6.3mm_D2.5mm_P7.62mm_Horizontal
SW1, SW2: SW_Push; button_pins
U1, U2, U3, U4: CD74HC4067M; multiplexer
U6: Power

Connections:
+24V: A2.8 (VMOT), A3.8 (VMOT), L1.1, U6.2 (24V)
/5v: A1.27 (+5V), A2.2 (VDD), A3.2 (VDD), I2C.2 (VCC), U1.24 (VCC), U2.24 (VCC), U3.24 (VCC), U4.24 (VCC)
/A0: A1.19 (A0), U1.13 (S3), U2.13 (S3), U3.13 (S3), U4.13 (S3)
/A1: A1.20 (A1), U1.14 (S2), U2.14 (S2), U3.14 (S2), U4.14 (S2)
/A2: A1.21 (A2), U1.11 (S1), U2.11 (S1), U3.11 (S1), U4.11 (S1)
/A3: A1.22 (A3), U1.10 (S0), U2.10 (S0), U3.10 (S0), U4.10 (S0)
/D2: A1.5 (D2), A3.16 (DIR)
/D3: A1.6 (D3), A3.15 (STEP)
/D4: A1.7 (D4), A2.16 (DIR)
/D5: A1.8 (D5), A2.15 (STEP)
/D6: A1.9 (D6), R1.1
/D7: A1.10 (D7), U2.15 (~E)
/D8: A1.11 (D8), U3.15 (~E)
/D9: A1.12 (D9), U4.15 (~E)
/D10: A1.13 (D10), SW1.2
/D11: A1.14 (D11), SW2.2
/D12: A1.15 (D12), U1.1 (COM), U2.1 (COM), U3.1 (COM), U4.1 (COM)
/D13: A1.16 (D13), U1.15 (~E)
/SCL: A1.24 (A5), I2C.4 (SCL)
/SDA: A1.23 (A4), I2C.3 (SDA)
GND: A1.29 (GND), A2.1 (GND), A2.7 (GND), A3.1 (GND), A3.7 (GND), I2C.1 (GND), Q1.3 (E), SW1.1, SW2.1, U1.12 (GND), U2.12 (GND), U3.12 (GND), U4.12 (GND), U6.1 (GND)
unnamed: A2.13 (~RESET), A2.14 (~SLEEP)
unnamed: A3.13 (~RESET), A3.14 (~SLEEP)
unnamed: Q1.1 (B), R1.2
unnamed: L1.2, Q1.2 (C)

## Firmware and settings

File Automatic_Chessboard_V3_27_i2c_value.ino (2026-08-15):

/*
 * Automatic Chessboard firmware 5.0.1.
 *
 * Substantially modified from "Automated Chessboard" by Greg06:
 * https://www.instructables.com/Automated-Chessboard/
 * Source and this adaptation: CC BY-NC-SA 4.0.
 * See ATTRIBUTION.md and LICENSE.md for lineage, changes, and exceptions.
 */

#include <EEPROM.h>
#include <avr/pgmspace.h>
#include "global.h"
#if defined(ACB_PROFILE_MKS_GEN_L_V1)
#include <SoftwareWire.h>
SoftwareWire acbLcdWire(LCD_SOFTWARE_SDA, LCD_SOFTWARE_SCL);
// hd44780_I2Cexp uses the Wire API by name. SoftwareWire supplies the same
// master API on MKS connector pins because SDA/SCL are not broken out there.
#define Wire acbLcdWire
#else
#include <Wire.h>
#include <SoftwareSerial.h>
#endif
#include <hd44780.h>
#include <hd44780ioClass/hd44780_I2Cexp.h>
#if defined(ACB_PROFILE_MKS_GEN_L_V1)
#undef Wire
#endif
#include "Micro_Max.h"

#define FIRMWARE_VERSION "5.0.1"

// All mutable firmware state is centralized here. global.h contains only
// types, configuration constants, enums, and extern declarations so changing
// hardware configuration cannot silently allocate a second copy of state.
BoardState reed_sensor_status = {{0}};
BoardState reed_sensor_record = {{0}};
BoardState turn_start_status = {{0}};
byte lifted_squares[2] = {NO_SQUARE, NO_SQUARE};
byte lifted_count = 0;
byte move_from = NO_SQUARE;
byte move_to = NO_SQUARE;
byte last_sensor_square = NO_SQUARE;
boolean last_sensor_occupied = false;
boolean human_move_ready = false;
boolean sensor_tracking_error = false;
boolean pending_move_displayed = false;
byte trolley_coordinate_X = CALIBRATION_PARK_FILE;
byte trolley_coordinate_Y = CALIBRATION_PARK_RANK;
boolean trolley_homed = false;
boolean motion_fault = false;
boolean magnet_state = false;
int minimum_free_ram = 32767;
unsigned long magnet_on_since = 0;
char mov[5] = {0, 0, 0, 0, 0};
byte sequence = start_up;
byte after_calibration = setup_check;

hd44780_I2Cexp lcd;
// Both profiles fan replies from hardware TX/D1 to USB and HC-08 RXD. The
// Nano receives on D10; MKS receives on Serial2 RX/D17 at EXP1 pin 3.
#if defined(ACB_PROFILE_MKS_GEN_L_V1)
#define bluetoothInput Serial2
#else
SoftwareSerial bluetoothInput(BLUETOOTH_RX, 1);
#endif

// The compact line protocol keeps the Nano responsible for motion and safety
// while a Windows host can provide full chess rules and Stockfish.
const byte HOST_INPUT_SIZE = 32;
struct HostInputBuffer {
  char data[HOST_INPUT_SIZE];
  byte length;
  byte flags;
};
const byte HOST_INPUT_OVERFLOWED = 1;
const byte HOST_VERSION_AGREED = 2;
HostInputBuffer usb_host_input = {{0}, 0, 0};
HostInputBuffer bluetooth_host_input = {{0}, 0, 0};
// 0=standalone, 1=reed-verified companion, 2=app-authoritative companion.
// A byte replaces the former boolean without increasing global SRAM.
byte remote_mode = 0;
boolean remote_human_white = true;
boolean remote_human_move_pending = false;
volatile boolean remote_stop_requested = false;
char remote_move_flags = 0;
char remote_promotion_piece = 0;

const unsigned int CAPTURE_DROP_SETTLE_MS = 400;

// Position records are journaled across multiple EEPROM slots. A new UNKNOWN
// record is committed before the first motor step, and a KNOWN record is
// committed only after the head reaches a stable logical position.
const byte POSITION_RECORD_VERSION = 1;
const byte POSITION_STATE_UNKNOWN = 0x5A;
const byte POSITION_STATE_KNOWN = 0xA5;
const byte POSITION_RECORD_COMMIT = 0xC3;
const byte POSITION_RECORD_SLOTS = 32;
const byte POSITION_RECORD_SIZE = 8;
int position_record_slot = -1;
unsigned int position_record_sequence = 0;
boolean trolley_position_known = false;
boolean calibration_lane_confirmed = false;
unsigned int last_home_white_steps = 0;
unsigned int last_home_black_steps = 0;

// Raw multiplexer rows follow the glued-tile wiring documented in
// windows_app/README.md. The installed sensor panel is rotated 180 degrees
// relative to the carriage frame, so normalize both axes once before any
// chess logic or host telemetry sees the board.
const byte SENSOR_ROW_MAP[8] PROGMEM = {7, 6, 1, 0, 3, 2, 5, 4};

byte logicalSensorRow(byte raw_row) {
  return 7 - pgm_read_byte(&SENSOR_ROW_MAP[raw_row]);
}

byte logicalSensorColumn(byte raw_column) {
  return 7 - raw_column;
}
boolean boardSquareOccupied(const BoardState &board, byte row, byte column) {
  return bitRead(board.rows[row], column);
}

void setBoardSquare(BoardState &board, byte row, byte column,
                    boolean occupied) {
  bitWrite(board.rows[row], column, occupied);
}

void requestCalibration(byte next_sequence) {
  after_calibration = next_sequence;
  calibration_lane_confirmed = false;
  if (trolley_position_known ||
      readControlPin(BUTTON_B_LIMIT_BLACK) == LOW) {
    sequence = calibration;
    showCalibration();
  }
  else {
    sequence = position_recovery;
    showPositionRecovery();
  }
}

void setup() {
  Serial.begin(9600);
  bluetoothInput.begin(9600);

  pinMode(MAGNET, OUTPUT);
  digitalWrite(MAGNET, LOW);

  pinMode(MOTOR_WHITE_STEP, OUTPUT);
  pinMode(MOTOR_WHITE_DIR, OUTPUT);
  pinMode(MOTOR_BLACK_STEP, OUTPUT);
  pinMode(MOTOR_BLACK_DIR, OUTPUT);
  digitalWrite(MOTOR_WHITE_STEP, LOW);
  digitalWrite(MOTOR_BLACK_STEP, LOW);

#if defined(ACB_PROFILE_MKS_GEN_L_V1)
  // Keep both integrated drivers disabled until STEP and DIR are known. Once
  // enabled they remain holding, matching the always-enabled Nano wiring and
  // preserving the calibrated CoreXY reference between moves.
  pinMode(MOTOR_WHITE_ENABLE, OUTPUT);
  pinMode(MOTOR_BLACK_ENABLE, OUTPUT);
  digitalWrite(MOTOR_WHITE_ENABLE,
               MOTOR_ENABLE_ACTIVE_LOW ? HIGH : LOW);
  digitalWrite(MOTOR_BLACK_ENABLE,
               MOTOR_ENABLE_ACTIVE_LOW ? HIGH : LOW);
#endif

  for (byte i = 0; i < 4; i++) {
    pinMode(MUX_ADDR[i], OUTPUT);
    digitalWrite(MUX_ADDR[i], LOW);
    pinMode(MUX_SELECT[i], OUTPUT);
    digitalWrite(MUX_SELECT[i], HIGH);
  }
  pinMode(MUX_OUTPUT, INPUT_PULLUP);

  pinMode(BUTTON_A_LIMIT_WHITE, INPUT_PULLUP);
#if defined(ACB_PROFILE_MKS_GEN_L_V1)
  pinMode(BUTTON_B_LIMIT_BLACK, INPUT_PULLUP);
#else
  // A6 has no digital input buffer or internal pull-up. The external 10 kOhm
  // pull-up makes a released switch read near 1023 and a pressed switch near 0.
#endif

  const int lcd_status = lcd.begin(16, 2);
  if (lcd_status) {
    Serial.print(F("LCDERR "));
    Serial.println(lcd_status);
  }
  lcd.backlight();
  loadPersistedTrolleyPosition();
  showPersistedTrolleyPosition();
  AI_reset();
  scanSensors();
  syncSensorState();
#if defined(ACB_PROFILE_MKS_GEN_L_V1)
  digitalWrite(MOTOR_WHITE_ENABLE,
               MOTOR_ENABLE_ACTIVE_LOW ? LOW : HIGH);
  digitalWrite(MOTOR_BLACK_ENABLE,
               MOTOR_ENABLE_ACTIVE_LOW ? LOW : HIGH);
#endif
  sequence = main_menu;
  showMainMenu();
  Serial.print(F("READY "));
  Serial.println(F(FIRMWARE_VERSION));
}

void loop() {
  if (enforceMagnetTimeout()) {
    sequence = fault_screen;
    showMotionFault();
  }
  processHostSerial();

  switch (sequence) {
    case main_menu:
      if (buttonPressed(BUTTON_A_LIMIT_WHITE)) {
        AI_reset();
        resetMoveTracker();
        requestCalibration(setup_check);
      }
      else if (buttonPressed(BUTTON_B_LIMIT_BLACK)) {
        requestCalibration(main_menu);
      }
      break;

    case position_recovery:
      if (buttonPressed(BUTTON_A_LIMIT_WHITE)) {
        calibration_lane_confirmed = true;
        sequence = calibration;
        showCalibration();
      }
      else if (buttonPressed(BUTTON_B_LIMIT_BLACK)) {
        returnToMainMenu();
      }
      break;

    case calibration:
      if (calibrateBoard()) {
        lcd.clear();
        lcd.print(F("CALIBRATION OK"));
        lcd.setCursor(0, 1);
        lcd.print(F("HEAD AT e6"));
        delay(1000);
        sequence = after_calibration;
        if (sequence == setup_check) showSetupCheck();
        else if (sequence == remote_setup_check) {
          if (remote_mode == 2) beginRemoteSession();
          else showRemoteSetupCheck();
        }
        else showMainMenu();
      }
      else {
        sequence = fault_screen;
        showMotionFault();
      }
      break;

    case setup_check:
      if (buttonPressed(BUTTON_A_LIMIT_WHITE)) {
        if (startingPositionIsValid()) {
          beginHumanTurn();
        }
        else {
          showStartingMismatch();
        }
      }
      else if (buttonPressed(BUTTON_B_LIMIT_BLACK)) {
        returnToMainMenu();
      }
      break;

    case player_white:
      updateSensorsAndTrackMove();
      if (human_move_ready && !pending_move_displayed) showPendingMove();
      if (buttonPressed(BUTTON_A_LIMIT_WHITE)) finishHumanTurn();
      break;

    case player_black:
      if (!blackPlayerMovement()) {
        sequence = fault_screen;
        showMotionFault();
      }
      else if (!physicalSensorsMatchExpected()) {
        sequence = ai_sensor_check;
        showAiSensorMismatch();
      }
      else {
        syncSensorState();
        beginHumanTurn();
      }
      break;

    case undo_required:
      scanSensors();
      if (recordMatchesTurnStart()) {
        syncSensorState();
        beginHumanTurn();
      }
      else if (buttonPressed(BUTTON_B_LIMIT_BLACK)) {
        returnToMainMenu();
      }
      break;

    case ai_sensor_check:
      if (buttonPressed(BUTTON_A_LIMIT_WHITE)) {
        if (physicalSensorsMatchExpected()) {
          if (move_from != NO_SQUARE) prepareManualAiPlacement();
          else {
            syncSensorState();
            beginHumanTurn();
          }
        }
        else showAiSensorMismatch();
      }
      else if (buttonPressed(BUTTON_B_LIMIT_BLACK)) {
        returnToMainMenu();
      }
      break;

    case game_over_screen:
      if (buttonPressed(BUTTON_B_LIMIT_BLACK) || buttonPressed(BUTTON_A_LIMIT_WHITE)) {
        returnToMainMenu();
      }
      break;

    case fault_screen:
      if (buttonPressed(BUTTON_A_LIMIT_WHITE)) {
        requestCalibration(main_menu);
      }
      else if (buttonPressed(BUTTON_B_LIMIT_BLACK)) {
        returnToMainMenu();
      }
      break;

    case remote_setup_check:
      if (buttonPressed(BUTTON_A_LIMIT_WHITE)) {
        if (startingPositionIsValid()) beginRemoteSession();
        else showStartingMismatch();
      }
      else if (buttonPressed(BUTTON_B_LIMIT_BLACK)) {
        stopRemoteSession();
      }
      break;

    case remote_human:
      updateSensorsAndTrackMove();
      if (human_move_ready && !pending_move_displayed) showRemotePendingMove();
      if (buttonPressed(BUTTON_B_LIMIT_BLACK)) stopRemoteSession();
      else if (buttonPressed(BUTTON_A_LIMIT_WHITE)) finishRemoteHumanTurn();
      break;

    case remote_wait_host:
      if (buttonPressed(BUTTON_B_LIMIT_BLACK)) stopRemoteSession();
      break;

    case remote_route_plan:
      // Button B always leaves the transaction safely idle with the magnet off.
      // A partially rearranged board then requires visual/sensor recovery before
      // another game; it is never silently committed as a chess move.
      if (buttonPressed(BUTTON_B_LIMIT_BLACK)) stopRemoteSession();
      break;

    case remote_undo_required:
      scanSensors();
      if (recordMatchesTurnStart()) {
        syncSensorState();
        beginRemoteHumanTurn();
      }
      else if (buttonPressed(BUTTON_B_LIMIT_BLACK)) {
        stopRemoteSession();
      }
      break;

    case remote_sensor_check:
      if (buttonPressed(BUTTON_A_LIMIT_WHITE)) {
        if (physicalSensorsMatchExpected()) {
          syncSensorState();
          finishRemoteComputerTurn();
        }
        else showRemoteSensorMismatch();
      }
      else if (buttonPressed(BUTTON_B_LIMIT_BLACK)) {
        stopRemoteSession();
      }
      break;

    case remote_promotion_wait:
      if (buttonPressed(BUTTON_A_LIMIT_WHITE)) {
        Serial.println(F("PROMOTION OK"));
        if (remote_mode == 2) waitForRemoteApp();
        else beginRemoteHumanTurn();
      }
      else if (buttonPressed(BUTTON_B_LIMIT_BLACK)) {
        stopRemoteSession();
      }
      break;
  }
}

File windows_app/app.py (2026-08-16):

"""Visual Windows control, monitoring, and development app for the chessboard."""

from __future__ import annotations

import json
import queue
import sys
import threading
import time
from collections import deque
from datetime import datetime
from pathlib import Path
import tkinter as tk
from tkinter import filedialog, messagebox, simpledialog, ttk

import chess
import chess.engine
import chess.pgn

from alignment import AlignmentPoint, GeometrySourceValues, calculate_geometry
from camera_source import CameraWorker
from model import (
    ManualSelection,
    MonitorModel,
    calibration_matches,
    expected_occupancy,
    head_move_matches,
    piece_move_matches,
    square_name,
)
from protocol import (
    AlignmentStatus,
    CommandRisk,
    GeometrySettings,
    alignment_command,
    classify_command,
    nudge_command,
    parse_alignment,
    parse_board_hex,
    parse_drag_command,
    parse_event,
    parse_geometry,
    parse_info,
    parse_telemetry,
    hello_command,
    SOFTWARE_VERSION,
    start_game_command,
)
from routing import MotionPlan, PlannerConfig, PlanningError, plan_chess_move
from support import EventRecorder, create_support_bundle, user_data_dir, write_json_atomic
from transports import (
    Hc08BleTransport,
    SimulatorTransport,
    UsbSerialTransport,
    discover_ble_devices,
    serial_ports,
)

APP_VERSION = SOFTWARE_VERSION
ROUTE_CONTROL_TIMEOUT_S = 8.0
ROUTE_MOTION_TIMEOUT_S = 75.0
START_ACK_TIMEOUT_MS = 8_000
APP_DIR = Path(__file__).resolve().parent
RUNTIME_DIR = Path(sys.executable).resolve().parent if getattr(sys, "frozen", False) else APP_DIR
DATA_DIR = user_data_dir()
SETTINGS_PATH = DATA_DIR / "settings.json"
LEGACY_SETTINGS_PATH = APP_DIR / "settings.json"
DEFAULT_STOCKFISH = RUNTIME_DIR / "stockfish" / "stockfish.exe"

PIECE_TEXT = {
    "P": "♙", "N": "♘", "B": "♗", "R": "♖", "Q": "♕", "K": "♔",
    "p": "♟", "n": "♞", "b": "♝", "r": "♜", "q": "♛", "k": "♚",
}

COLORS = {
    "good": "#207a3c",
    "warn": "#a15c00",
    "bad": "#ad2532",
    "muted": "#637083",
    "accent": "#2067b2",
    "panel": "#f4f6f8",
}


class ChessboardCanvas(tk.Canvas):
    """Logical pieces plus physical reed occupancy and carriage position."""

    def __init__(self, master, size: int = 560):
        super().__init__(master, width=size, height=size, highlightthickness=1,
                         highlightbackground="#9ba5b1", background="#ffffff")
        self.board = chess.Board()
        self.sensors: frozenset[int] | None = None
        self.flipped = False
        self.last_move: chess.Move | None = None
        self.carriage: tuple[int, int] | None = None
        self.selected_squares: frozenset[int] = frozenset()
        self.on_square_clicked = None
        self.bind("<Configure>", lambda _event: self.redraw())
        self.bind("<Button-1>", self._clicked)

    def set_state(self, board: chess.Board, sensors: frozenset[int] | None,
                  flipped: bool, carriage: tuple[int, int] | None = None) -> None:
        self.board = board.copy(stack=False)
        self.sensors = sensors
        self.flipped = flipped
        self.last_move = board.peek() if board.move_stack else None
        self.carriage = carriage
        self.redraw()

    def set_interaction(self, selected: frozenset[int], callback) -> None:
        changed = selected != self.selected_squares or callback != self.on_square_clicked
        self.selected_squares = selected
        self.on_square_clicked = callback
        self.configure(cursor="hand2" if callback else "")
        if changed:
            self.redraw()

    def _clicked(self, event) -> None:
        if not self.on_square_clicked:
            return
        width, height = max(self.winfo_width(), 160), max(self.winfo_height(), 160)
        size = min(width, height)
        offset_x, offset_y = (width - size) / 2, (height - size) / 2
        if not (offset_x <= event.x < offset_x + size and offset_y <= event.y < offset_y + size):
            return
        display_file = min(7, int((event.x - offset_x) / (size / 8)))
        display_rank = min(7, int((event.y - offset_y) / (size / 8)))
        file_index = 7 - display_file if self.flipped else display_file
        rank_index = display_rank if self.flipped else 7 - display_rank
        self.on_square_clicked(chess.square(file_index, rank_index))

    def _display_coordinates(self, square: int) -> tuple[int, int]:
        file_index = chess.square_file(square)
        rank_index = chess.square_rank(square)
        if self.flipped:
            return 7 - file_index, rank_index
        return file_index, 7 - rank_index

    def redraw(self) -> None:
        self.delete("all")
        width = max(self.winfo_width(), 160)
        height = max(self.winfo_height(), 160)
        size = min(width, height)
        offset_x = (width - size) / 2
        offset_y = (height - size) / 2
        square_size = size / 8
        expected = expected_occupancy(self.board)
        missing = expected - self.sensors if self.sensors is not None else frozenset()
        unexpected = self.sensors - expected if self.sensors is not None else frozenset()

        for display_rank in range(8):
            for display_file in range(8):
                file_index = 7 - display_file if self.flipped else display_file
                rank_index = display_rank if self.flipped else 7 - display_rank
                square = chess.square(file_index, rank_index)
                x0 = offset_x + display_file * square_size
                y0 = offset_y + display_rank * square_size
                fill = "#f0d9b5" if (file_index + rank_index) % 2 else "#b58863"
                if self.last_move and square in (self.last_move.from_square, self.last_move.to_square):
                    fill = "#d7c75b" if fill == "#f0d9b5" else "#aa9b3d"
                self.create_rectangle(x0, y0, x0 + square_size, y0 + square_size,
                                      fill=fill, outline=fill)
                if square in self.selected_squares:
                    inset = max(2, square_size * 0.04)
                    self.create_rectangle(
                        x0 + inset, y0 + inset, x0 + square_size - inset,
                        y0 + square_size - inset, outline="#f4c542",
                        width=max(3, int(square_size / 14)),
                    )

                piece = self.board.piece_at(square)
                if piece:
                    self.create_text(
                        x0 + square_size / 2, y0 + square_size / 2,
                        text=PIECE_TEXT[piece.symbol()],
                        font=("Segoe UI Symbol", max(12, int(square_size * 0.66))),
                    )
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

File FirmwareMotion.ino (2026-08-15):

/* CoreXY stepping, calibration, persistence transitions, and path planning. */

// ---------------------------- Calibration/motion -------------------------

void configureMotorDirection(byte direction) {
  digitalWrite(MOTOR_WHITE_DIR,
               (direction == R_L || direction == T_B || direction == RL_TB) ? HIGH : LOW);
  digitalWrite(MOTOR_BLACK_DIR,
               (direction == B_T || direction == R_L || direction == RL_BT) ? HIGH : LOW);
}

void tripRemoteEmergencyStop() {
  if (remote_stop_requested) return;
  remote_stop_requested = true;
  motion_fault = true;
  trolley_homed = false;
  setMagnet(false);
  sequence = fault_screen;
  showMotionFault();
  Serial.println(F("ESTOP REMOTE"));
}

boolean drainForEmergencyStop(Stream &input, HostInputBuffer &buffer) {
  boolean requested = false;
  while (input.available()) {
    char value = input.read();
    if (value == '!') requested = true;
    if (value == '\r' || value == '\n') {
      buffer.flags &= ~HOST_INPUT_OVERFLOWED;
    }
    else if (value >= 32 && value <= 126 && value != '!' &&
             !(buffer.flags & HOST_INPUT_OVERFLOWED)) {
      buffer.flags |= HOST_INPUT_OVERFLOWED;
      sendHostError(F("BUSY"));
    }
    buffer.length = 0;
  }
  return requested;
}

boolean pollRemoteEmergencyStop() {
  if (enforceMagnetTimeout()) return true;
  if (remote_stop_requested) return true;
  boolean requested = drainForEmergencyStop(Serial, usb_host_input);
  if (drainForEmergencyStop(bluetoothInput, bluetooth_host_input)) requested = true;
  if (!requested) return false;
  tripRemoteEmergencyStop();
  return true;
}

boolean pulseMotor(byte direction, unsigned int speed_delay, unsigned int steps, boolean monitor_stops) {
  if (monitor_stops && motion_fault) return false;
  if (steps == 0) return true;
  markTrolleyPositionUnknown();
  configureMotorDirection(direction);
  delayMicroseconds(2);

  for (unsigned int step_count = 0; step_count < steps; step_count++) {
    if ((step_count & 7) == 0 && pollRemoteEmergencyStop()) return false;
    if (monitor_stops &&
        (readControlPin(BUTTON_A_LIMIT_WHITE) == LOW ||
         readControlPin(BUTTON_B_LIMIT_BLACK) == LOW)) {
      motion_fault = true;
      trolley_homed = false;
      setMagnet(false);
      return false;
    }

    unsigned int low_time = speed_delay * 2U - MOTOR_STEP_PULSE_US;

    digitalWrite(MOTOR_WHITE_STEP,
                 (direction == LR_TB || direction == RL_BT) ? LOW : HIGH);
    digitalWrite(MOTOR_BLACK_STEP,
                 (direction == LR_BT || direction == RL_TB) ? LOW : HIGH);
    delayMicroseconds(MOTOR_STEP_PULSE_US);
    digitalWrite(MOTOR_WHITE_STEP, LOW);
    digitalWrite(MOTOR_BLACK_STEP, LOW);
    delayMicroseconds(low_time);
  }
  return true;
}

boolean pulseCoreXYQueenSegment(int delta_x_steps, int delta_y_steps,
                                unsigned int speed_delay,
                                boolean monitor_stops) {
  if (monitor_stops && motion_fault) return false;

  // CoreXY transform for the existing motor polarity:
  // white = +X -Y, black = -X -Y.
  long white_delta = (long)delta_x_steps - delta_y_steps;
  long black_delta = -(long)delta_x_steps - delta_y_steps;
  unsigned int white_steps =
      (unsigned int)(white_delta < 0 ? -white_delta : white_delta);
  unsigned int black_steps =
      (unsigned int)(black_delta < 0 ? -black_delta : black_delta);
  unsigned int event_count = max(white_steps, black_steps);
  if (event_count == 0) return true;
  boolean step_white = white_steps != 0;
  boolean step_black = black_steps != 0;

  markTrolleyPositionUnknown();
  digitalWrite(MOTOR_WHITE_DIR, white_delta >= 0 ? HIGH : LOW);
  digitalWrite(MOTOR_BLACK_DIR, black_delta >= 0 ? HIGH : LOW);
  delayMicroseconds(2);

  for (unsigned int event = 0; event < event_count; event++) {
    if ((event & 7) == 0 && pollRemoteEmergencyStop()) return false;
    if (monitor_stops &&
        (readControlPin(BUTTON_A_LIMIT_WHITE) == LOW ||
         readControlPin(BUTTON_B_LIMIT_BLACK) == LOW)) {
      motion_fault = true;
      trolley_homed = false;
      setMagnet(false);
      return false;
    }

    unsigned int low_time = speed_delay * 2U - MOTOR_STEP_PULSE_US;
    digitalWrite(MOTOR_WHITE_STEP, step_white ? HIGH : LOW);
    digitalWrite(MOTOR_BLACK_STEP, step_black ? HIGH : LOW);
    delayMicroseconds(MOTOR_STEP_PULSE_US);
    digitalWrite(MOTOR_WHITE_STEP, LOW);
    digitalWrite(MOTOR_BLACK_STEP, LOW);
    delayMicroseconds(low_time);
  }
  return true;
}

boolean pulseCoreXYLine(int delta_x_steps, int delta_y_steps,
                        unsigned int speed_delay, boolean monitor_stops) {
  // Full stepping on the physical mechanism is reliable only when each
  // Cartesian segment is horizontal, vertical, or an exact 45-degree
  // diagonal. Never interpolate unequal X/Y step ratios. Split every other
  // displacement into one diagonal segment followed by one axial segment so
  // this invariant applies to every motion caller, not only chess paths.
  unsigned int x_steps = abs(delta_x_steps);
  unsigned int y_steps = abs(delta_y_steps);
  if (!x_steps || !y_steps || x_steps == y_steps) {
    return pulseCoreXYQueenSegment(delta_x_steps, delta_y_steps,
                                   speed_delay, monitor_stops);
  }

  int diagonal_steps = min(x_steps, y_steps);
  int diagonal_x = delta_x_steps < 0 ? -diagonal_steps : diagonal_steps;
  int diagonal_y = delta_y_steps < 0 ? -diagonal_steps : diagonal_steps;
  if (!pulseCoreXYQueenSegment(diagonal_x, diagonal_y,
                               speed_delay, monitor_stops)) return false;
  return pulseCoreXYQueenSegment(delta_x_steps - diagonal_x,
                                 delta_y_steps - diagonal_y,
                                 speed_delay, monitor_stops);
}

boolean pulseCoreXYCorridor(int first_x, int first_y,
                            int middle_x, int middle_y,
                            int last_x, int last_y,
                            unsigned int speed_delay, boolean monitor_stops) {
  // Keep carried pieces on explicit clearance lanes. Besides being easier to
  // inspect than an interpolated curve, three exact lines avoid the repeated
  // short CoreXY direction/step-ratio changes that can lose full steps.
  if (!pulseCoreXYLine(first_x, first_y, speed_delay, monitor_stops))
    return false;
  if (!pulseCoreXYLine(middle_x, middle_y, speed_delay, monitor_stops))
    return false;
  return pulseCoreXYLine(last_x, last_y, speed_delay, monitor_stops);
}
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

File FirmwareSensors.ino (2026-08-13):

/* Packed reed-matrix scanning and physical move tracking. */

// ---------------------------- Sensor handling ----------------------------

void scanSensors() {
  byte column = 6;
  byte row = 0;

  for (byte mux = 0; mux < 4; mux++) {
    digitalWrite(MUX_SELECT[mux], LOW);
    for (byte channel = 0; channel < 16; channel++) {
      for (byte bit_number = 0; bit_number < 4; bit_number++) {
        digitalWrite(MUX_ADDR[bit_number], (channel >> bit_number) & 1);
      }
      // Three-sample majority filtering rejects short multiplexer/reed glitches.
      delayMicroseconds(20);
      byte high_votes = digitalRead(MUX_OUTPUT);
      delayMicroseconds(30);
      high_votes += digitalRead(MUX_OUTPUT);
      delayMicroseconds(30);
      high_votes += digitalRead(MUX_OUTPUT);
      byte raw_row = 7 - column;
      setBoardSquare(reed_sensor_record, logicalSensorRow(raw_row),
                     logicalSensorColumn(row), high_votes < 2);
      row++;
      if (channel == 7) {
        column++;
        row = 0;
      }
    }
    digitalWrite(MUX_SELECT[mux], HIGH);
    if (mux == 0) column = 4;
    else if (mux == 1) column = 2;
    else if (mux == 2) column = 0;
    row = 0;
  }
}

void syncSensorState() {
  copySensorTable(reed_sensor_record, reed_sensor_status);
  copySensorTable(reed_sensor_record, turn_start_status);
  resetMoveTracker();
}

void copySensorTable(const BoardState &source, BoardState &destination) {
  memcpy(destination.rows, source.rows, sizeof(destination.rows));
}

byte countOccupied(const BoardState &table) {
  byte occupied = 0;
  for (byte row = 0; row < 8; row++) {
    byte bits = table.rows[row];
    while (bits) {
      bits &= bits - 1;
      occupied++;
    }
  }
  return occupied;
}

boolean startingPositionIsValid() {
  scanSensors();
  for (byte row = 0; row < 8; row++) {
    byte expected = (row < 2 || row > 5) ? 0xFF : 0;
    if (reed_sensor_record.rows[row] != expected) return false;
  }
  syncSensorState();
  return true;
}

boolean physicalSensorsMatchExpected() {
  scanSensors();
  return memcmp(reed_sensor_record.rows, reed_sensor_status.rows,
                sizeof(reed_sensor_record.rows)) == 0;
}

boolean recordMatchesTurnStart() {
  return memcmp(reed_sensor_record.rows, turn_start_status.rows,
                sizeof(reed_sensor_record.rows)) == 0;
}

void resetMoveTracker() {
  lifted_squares[0] = NO_SQUARE;
  lifted_squares[1] = NO_SQUARE;
  lifted_count = 0;
  move_from = NO_SQUARE;
  move_to = NO_SQUARE;
  human_move_ready = false;
  sensor_tracking_error = false;
  pending_move_displayed = false;
}

void updateSensorsAndTrackMove() {
  scanSensors();
  for (byte row = 0; row < 8; row++) {
    for (byte column = 0; column < 8; column++) {
      boolean old_occupied = boardSquareOccupied(reed_sensor_status,
                                                  row, column);
      boolean new_occupied = boardSquareOccupied(reed_sensor_record,
                                                  row, column);
      if (old_occupied == new_occupied) continue;

      byte square = row * 8 + column;
      last_sensor_square = square;
      last_sensor_occupied = new_occupied;

      if (!human_move_ready) {
        if (old_occupied && !new_occupied) recordLift(square);
        else if (!old_occupied && new_occupied) recordPlacement(square);
      }
      setBoardSquare(reed_sensor_status, row, column, new_occupied);
    }
  }
}

void recordLift(byte square) {
  for (byte i = 0; i < lifted_count; i++) {
    if (lifted_squares[i] == square) return;
  }
  if (lifted_count >= 2) {
    sensor_tracking_error = true;
    return;
  }
  lifted_squares[lifted_count++] = square;
}

void recordPlacement(byte destination) {
  if (lifted_count == 0) return;

  byte source = NO_SQUARE;
  // Captures are performed by lifting the moving piece first. Prefer that
  // first lift so en-passant (whose captured pawn is not on the destination)
  // is reported correctly; fall back for a lift-and-replace gesture.
  for (byte i = 0; i < lifted_count; i++) {
    byte candidate = lifted_squares[i];
    if (candidate != destination) {
      source = candidate;
      break;
    }
  }
  if (source == NO_SQUARE) return;

  move_from = source;
  move_to = destination;
  human_move_ready = true;
}

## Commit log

2026-07-24 Import current automatic chessboard firmware
2026-07-24 Optimize CoreXY motor motion
2026-07-24 Park captured pieces safely off-board
2026-07-24 Use calibration-side capture bin
2026-07-24 Keep calibration clear of corner switch lane
2026-07-24 Persist trolley position across power cycles
2026-07-24 Use precise normal calibration switches
2026-07-24 Limit backoff in all calibration paths
2026-07-24 Raise calibration switch release limit
2026-07-24 Simplify calibration switch handling
2026-07-30 Add configurable sensor rank profiles
2026-07-30 Simplify fixed sensor rank mapping
    [Automatic_Chessboard_V3_27_i2c_value.ino, app.py, diagnose_board.py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]
2026-07-30 Add hardware build and safety guide
    [automatic_chessboard_copy.kicad_pcb, bom.csv, connections.csv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]
2026-07-30 Add guided wiring simulation
2026-07-31 Fix LCD initialization compatibility
    [Automatic_Chessboard_V3_27_i2c_value.ino]
2026-08-08 Add print files and complete hardware documentation
    [back_case_spacer_left_tpu.stl, back_case_spacer_right_tpu.stl, bom.csv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]
2026-08-08 Document working prototype enclosure and PCB rework
    [bom.csv]
2026-08-09 Add app-guided calibration and square movement
2026-08-09 Correct the physical sensor coordinate frame
    [Automatic_Chessboard_V3_27_i2c_value.ino, app.py, transports.py]
2026-08-10 Document STEP and DIR pull-downs
    [bom.csv, connections.csv]
2026-08-11 invalidate mobile calibration after motion faults
2026-08-11 stabilize full-speed board motion
    [FirmwareHost.ino, FirmwareMotion.ino, FirmwarePieces.ino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]
2026-08-12 add collision-safe host routing and motionless validation
    [Automatic_Chessboard_V3_27_i2c_value.ino, FirmwareHost.ino, app.py]
2026-08-13 add guided persistent board calibration
2026-08-13 replace persistent offsets with local geometry setup
    [Automatic_Chessboard_V3_27_i2c_value.ino, FirmwareHost.ino, FirmwareMotion.ino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]
2026-08-13 add supported MKS Gen L controller profile
    [mks-gen-l-v1-connections.csv]
2026-08-14 Document motor wiring interference controls
2026-08-14 enforce queen-aligned carriage motion
2026-08-14 release compact board alignment workflow
2026-08-14 Add app-authoritative play without reed switches
2026-08-16 Avoid duplicate corridor searches
    [routing.py]
2026-08-26 Stabilize board selection controls
2026-08-26 Refactor board simulator into immersive R3F experience
2026-08-26 Fix capture homing and toggleable simulator modes
    [firmware-core.js]
2026-09-15 Add prototype demo section to README
2026-09-15 Embed prototype video in README
